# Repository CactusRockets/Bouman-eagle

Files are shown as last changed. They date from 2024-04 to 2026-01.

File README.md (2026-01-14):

# Avionics Boards for the Bouman-3KM Rocket

This repository contains the design files for the avionics boards used in the **Bouman 3 km rocket**, developed by **Cactus Rockets Design**.

## Description

The avionics system is composed of the following boards:

- **COTS Board**
- **Processing Board**
- **Actuation Board**
- **Battery Board**

The **COTS Board** is responsible for measuring pressure, altitude, acceleration, and the rocket’s orientation.

The **Processing Board** handles the processing of data received from the COTS board and the GPS module, stores this data, and transmits it via telemetry.

The **Actuation Board** contains the circuitry required to correctly activate the squibs (skibs) used in the recovery system.

The **Battery Board** distributes the battery voltages to connectors so they can be easily used by the other boards.

> **Note:** All board files can be opened using **Autodesk Eagle** software.

## Schematics and Layouts

### COTS Board
cots1
cots2

### Processing Board
processamento1
processamento2

### Actuation Board
acionamento1
acionamento2

### Battery Board
baterias1
baterias2

## System Operation

Both the **COTS Board** and the **Processing Board** include activation switches. The system startup sequence is as follows:

1. Activate the switch on the COTS Board.
2. Activate the switch on the Processing Board.

After each sensor reading, the data is stored on a microSD card and transmitted via telemetry.

When the COTS board detects the rocket’s descent, it sends a signal to the Actuation Board, which then triggers the squib responsible for deploying the **drogue parachute**.

During the descent with only the drogue parachute deployed, once the rocket reaches an altitude below **500 meters**, the system detects this condition and activates the second squib. This action deploys the **main parachute**, ensuring a stable and controlled descent of the rocket until touchdown.

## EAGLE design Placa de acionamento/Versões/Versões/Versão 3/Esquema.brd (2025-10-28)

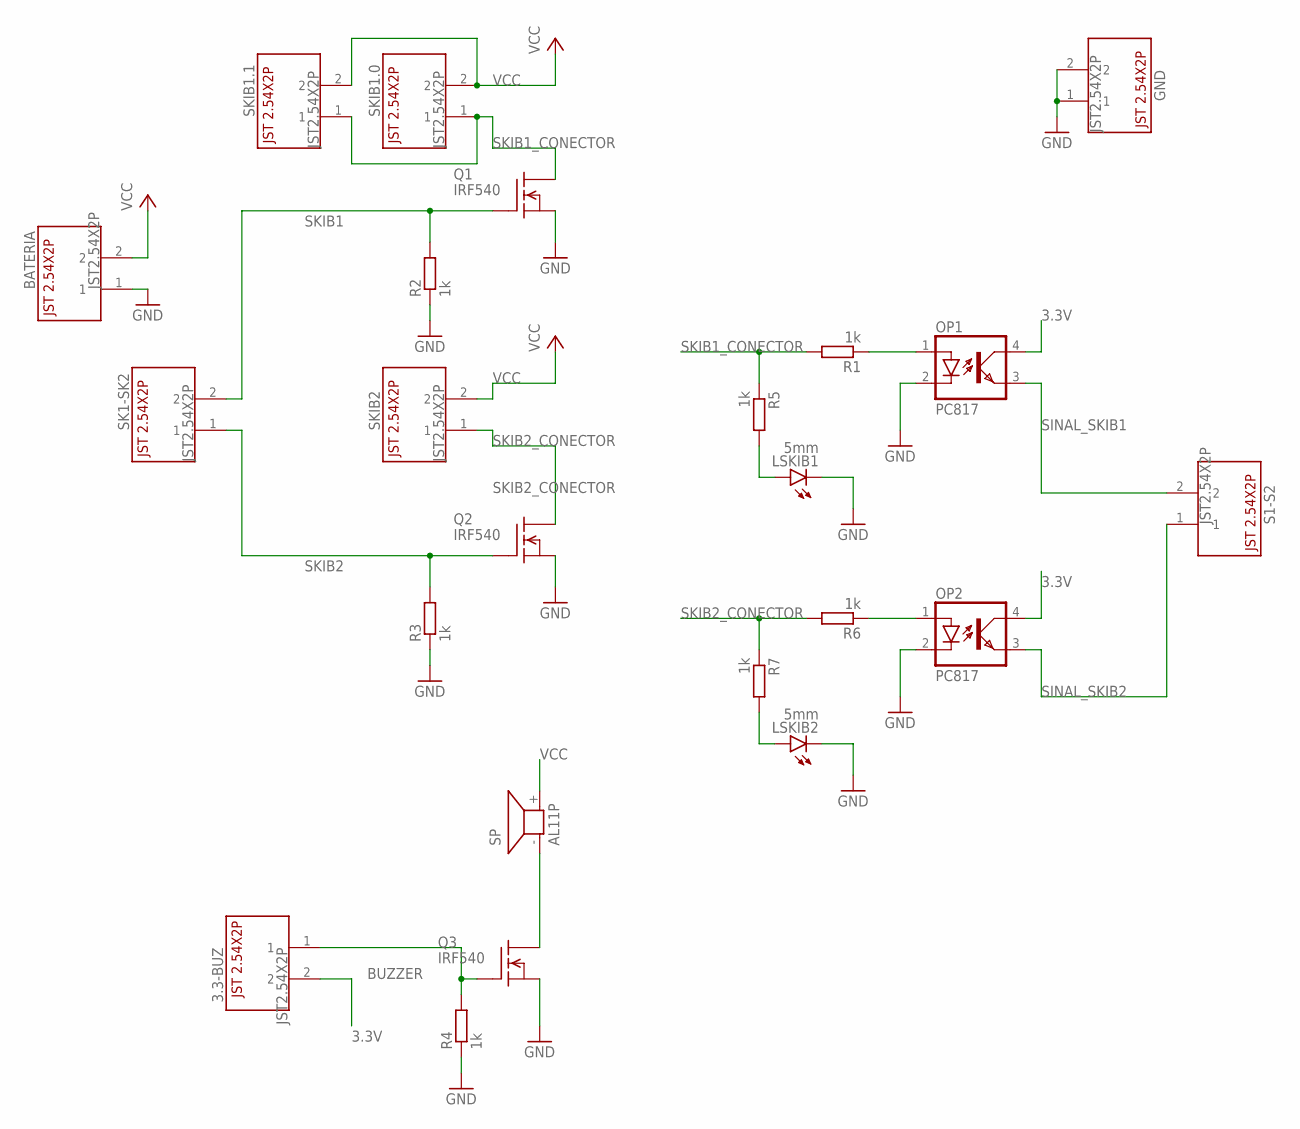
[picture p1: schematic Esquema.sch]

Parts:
3.3-BUZ: JST2.54X2P; JST2.54X2P_FOOTPRINT
BATERIA: JST2.54X2P; JST2.54X2P_FOOTPRINT
GND: JST2.54X2P; JST2.54X2P_FOOTPRINT
LSKIB1, LSKIB2: 5mm; LED5MM
OP1, OP2: PC817; DIL04
Q1, Q2, Q3: IRF540; TO220
R1, R2, R3, R4, R5, R6, R7: 1k; 0207/10
S1-S2: JST2.54X2P; JST2.54X2P_FOOTPRINT
SK1-SK2: JST2.54X2P; JST2.54X2P_FOOTPRINT
SKIB1.0, SKIB1.1, SKIB2: JST2.54X2P; JST2.54X2P_FOOTPRINT
SP: AL11P

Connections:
3.3V: 3.3-BUZ.2, OP1.4 (COL), OP2.4 (COL)
BUZZER: 3.3-BUZ.1, Q3.1 (G), R4.2
GND: BATERIA.1, GND.1, GND.2, LSKIB1.K (C), LSKIB2.K (C), OP1.2 (C), OP2.2 (C), Q1.3 (S), Q2.3 (S), Q3.3 (S), R2.1, R3.1, R4.1
unnamed: LSKIB2.A, R7.2
unnamed: Q3.2 (D), SP.- (1)
unnamed: LSKIB1.A, R5.2
unnamed: OP1.1 (A), R1.1
unnamed: OP2.1 (A), R6.1
SINAL_SKIB1: OP1.3 (EMIT), S1-S2.2
SINAL_SKIB2: OP2.3 (EMIT), S1-S2.1
SKIB1: Q1.1 (G), R2.2, SK1-SK2.2
SKIB1_CONECTOR: Q1.2 (D), R1.2, R5.1, SKIB1.0.1, SKIB1.1.1
SKIB2: Q2.1 (G), R3.2, SK1-SK2.1
SKIB2_CONECTOR: Q2.2 (D), R6.2, R7.1, SKIB2.1
VCC: BATERIA.2, SKIB1.0.2, SKIB1.1.2, SKIB2.2, SP.+ (2)

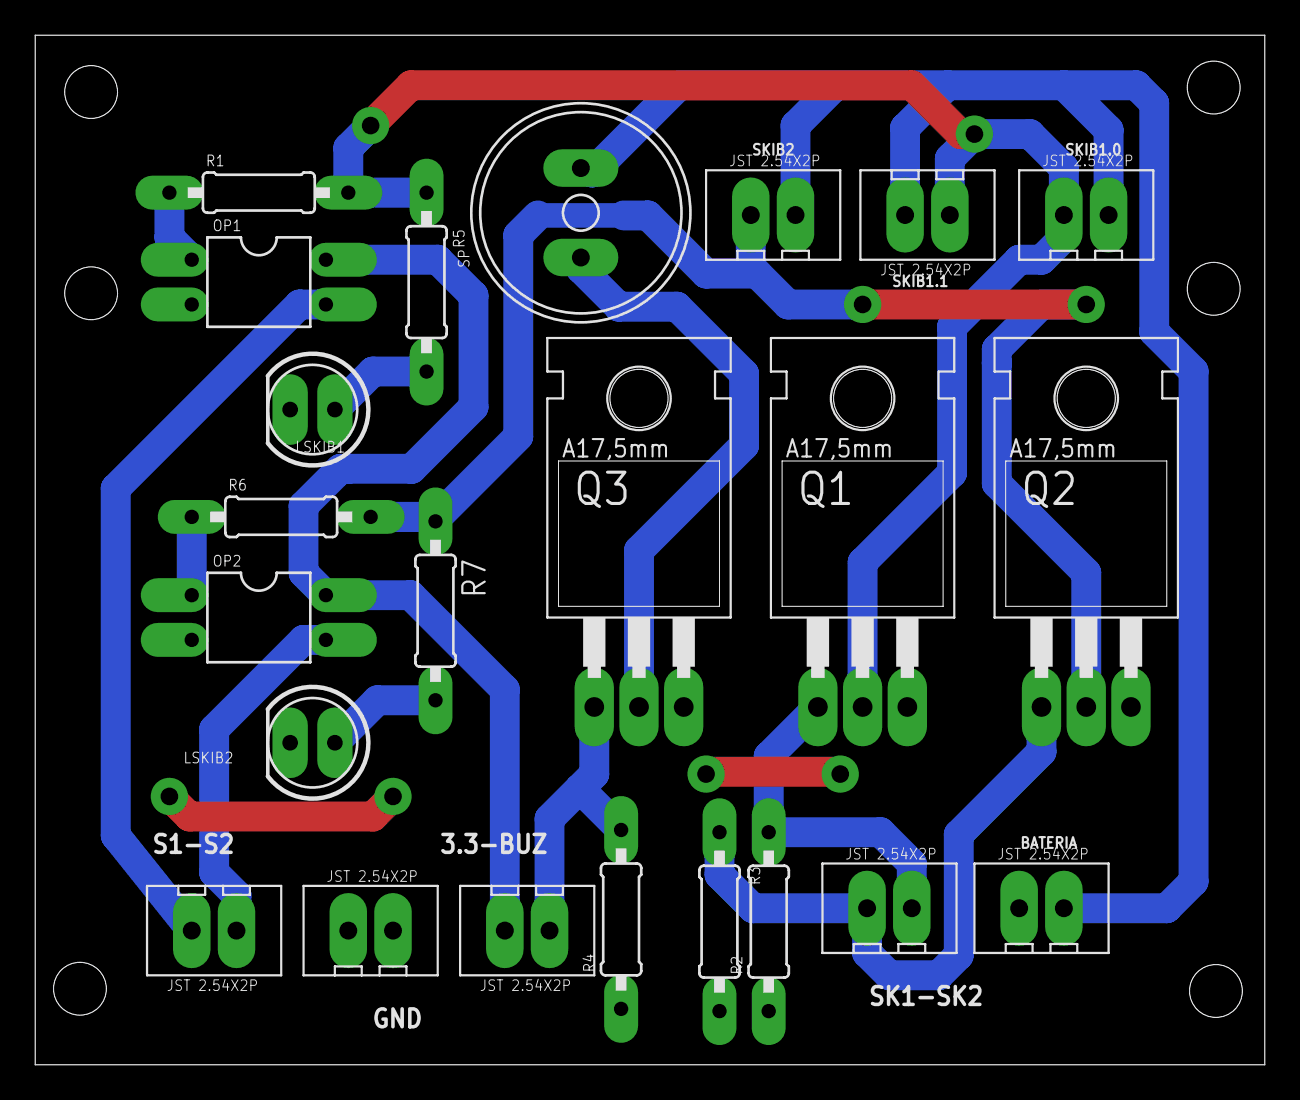
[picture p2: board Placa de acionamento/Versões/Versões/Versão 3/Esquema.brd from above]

Board: 2 copper layers, 69.8 x 58.5 mm, 23 parts (0 on the bottom side), 15 nets.

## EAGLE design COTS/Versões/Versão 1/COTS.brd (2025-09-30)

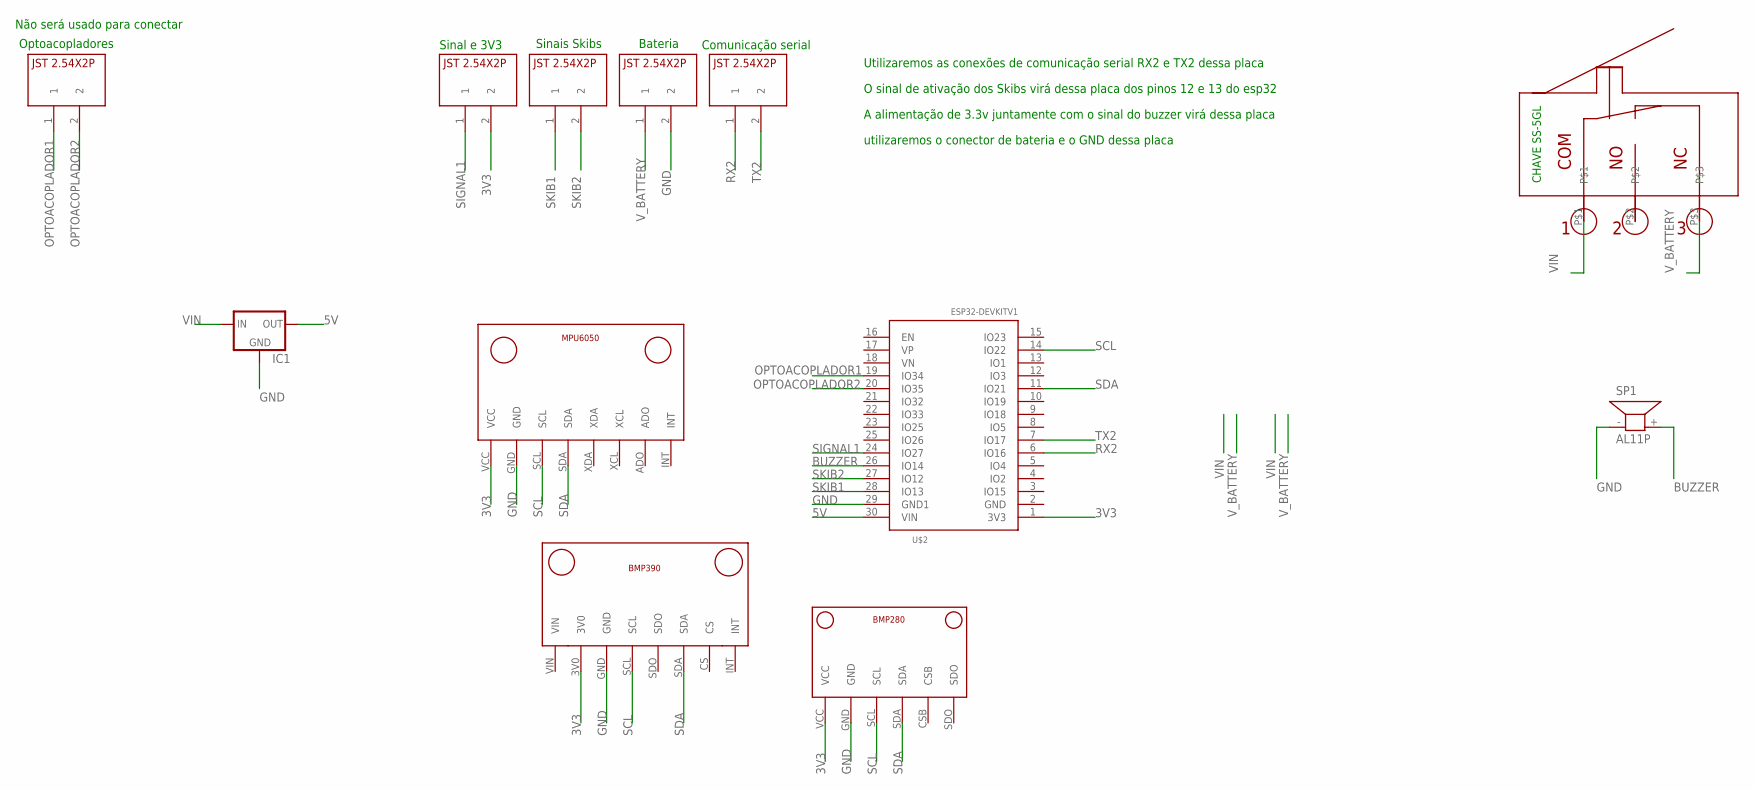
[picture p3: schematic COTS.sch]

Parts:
IC1: 78XXL
SP1: AL11P
U$1: MPU6050V1; MPU6050_FOOTPRINT
U$2: ESP32DEVKITV1; ESP32-DEVKITV1
U$3: BMP390V1; BMP390_FOOTPRINT
U$4, U$5, U$6, U$7, U$9: JST2.54X2P; JST2.54X2P_FOOTPRINT
U$8: CHAVE_SS-5GL; CHAVESS-5GL
U$10: BMP280V1; BMP280_FOOTPRINT

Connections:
3V3: U$1.VCC, U$2.1 (3V3), U$3.3V0, U$5.2, U$10.VCC
5V: IC1.OUT, U$2.30 (VIN)
BUZZER: SP1.+ (2), U$2.26 (IO14)
GND: IC1.GND, SP1.- (1), U$1.GND, U$2.29 (GND1), U$3.GND, U$6.2, U$10.GND
OPTOACOPLADOR1: U$2.19 (IO34), U$9.1
OPTOACOPLADOR2: U$2.20 (IO35), U$9.2
RX2: U$2.6 (IO16), U$7.1
SCL: U$1.SCL, U$2.14 (IO22), U$3.SCL, U$10.SCL
SDA: U$1.SDA, U$2.11 (IO21), U$3.SDA, U$10.SDA
SIGNAL1: U$2.24 (IO27), U$5.1
SKIB1: U$2.28 (IO13), U$4.1
SKIB2: U$2.27 (IO12), U$4.2
TX2: U$2.7 (IO17), U$7.2
VIN: IC1.IN, U$8.P$1
V_BATTERY: U$6.1, U$8.P$3

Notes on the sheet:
Sinais Skibs
Sinal e 3V3
Bateria
Comunicação serial
Optoacopladores
Utilizaremos as conexões de comunicação serial RX2 e TX2 dessa placa
O sinal de ativação dos Skibs virá dessa placa dos pinos 12 e 13 do esp32
A alimentação de 3.3v juntamente com o sinal do buzzer virá dessa placa
utilizaremos o conector de bateria e o GND dessa placa
Não será usado para conectar

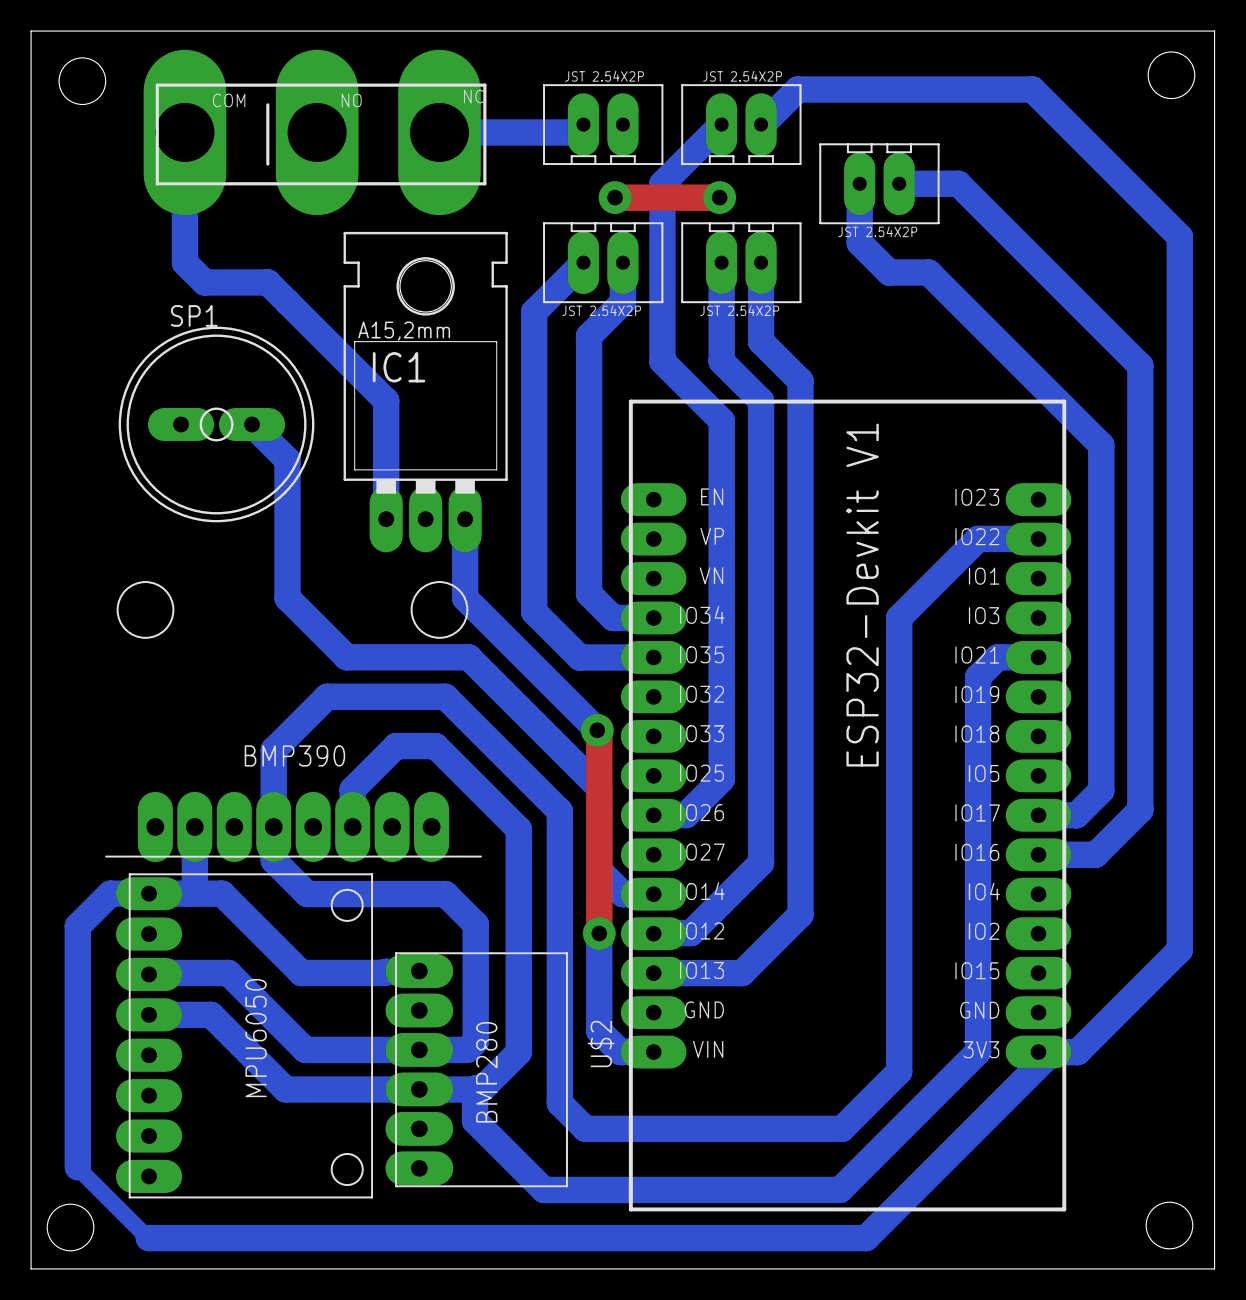
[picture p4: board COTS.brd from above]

Board: 2 copper layers, 76.2 x 79.7 mm, 12 parts (0 on the bottom side), 15 nets.

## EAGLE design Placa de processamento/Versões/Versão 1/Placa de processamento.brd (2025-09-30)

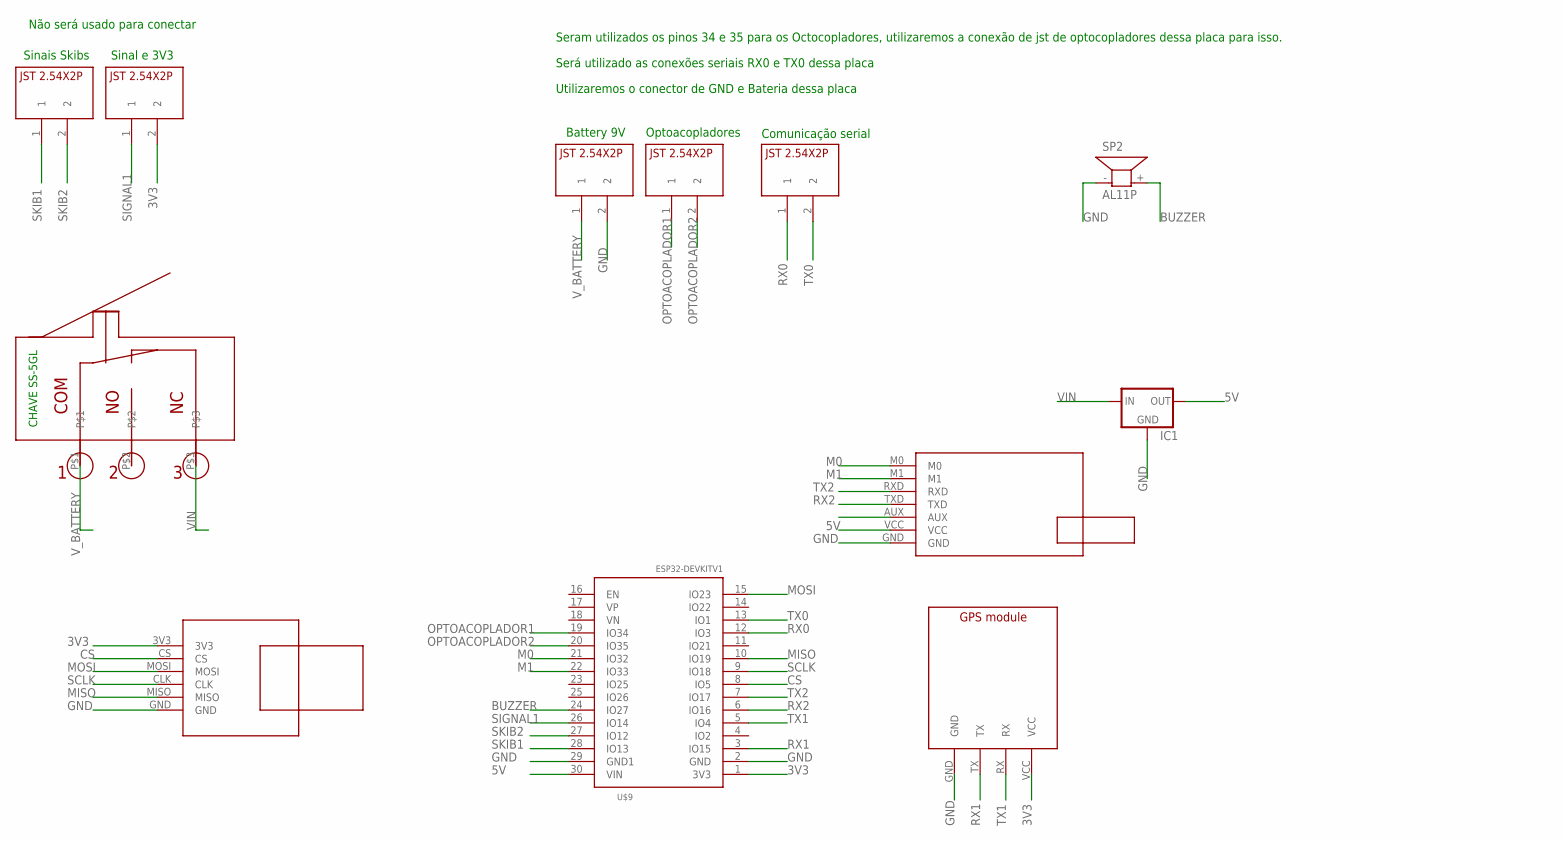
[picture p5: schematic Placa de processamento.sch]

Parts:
IC1: 78XXL
SP2: AL11P
U$2: MICROSD_SMALL_READER; MICROSD_SMALL_READER_FOOTPRINT
U$3, U$4, U$5, U$6, U$10: JST2.54X2P; JST2.54X2P_FOOTPRINT
U$7: GPS_MODULE; GPS_MODULE_FOOTPRINT
U$8: E22-400T30D; E22-400T30D_FOOTPRINT
U$9: ESP32DEVKITV1; ESP32-DEVKITV1
U$11: CHAVE_SS-5GL; CHAVESS-5GL

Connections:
3V3: U$2.3V3, U$5.2, U$7.VCC, U$9.1 (3V3)
5V: IC1.OUT, U$8.VCC, U$9.30 (VIN)
BUZZER: SP2.+ (2), U$9.24 (IO27)
CS: U$2.CS, U$9.8 (IO5)
GND: IC1.GND, SP2.- (1), U$2.GND, U$3.2, U$7.GND, U$8.GND, U$9.2 (GND), U$9.29 (GND1)
M0: U$8.M0, U$9.21 (IO32)
M1: U$8.M1, U$9.22 (IO33)
MISO: U$2.MISO, U$9.10 (IO19)
MOSI: U$2.MOSI, U$9.15 (IO23)
OPTOACOPLADOR1: U$6.1, U$9.19 (IO34)
OPTOACOPLADOR2: U$6.2, U$9.20 (IO35)
RX0: U$9.12 (IO3), U$10.1
RX1: U$7.TX, U$9.3 (IO15)
RX2: U$8.TXD, U$9.6 (IO16)
SCLK: U$2.CLK, U$9.9 (IO18)
SIGNAL1: U$5.1, U$9.26 (IO14)
SKIB1: U$4.1, U$9.28 (IO13)
SKIB2: U$4.2, U$9.27 (IO12)
TX0: U$9.13 (IO1), U$10.2
TX1: U$7.RX, U$9.5 (IO4)
TX2: U$8.RXD, U$9.7 (IO17)
VIN: IC1.IN, U$11.P$3
V_BATTERY: U$3.1, U$11.P$1

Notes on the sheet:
Battery 9V
Sinais Skibs
Sinal e 3V3
Optoacopladores
Comunicação serial
Seram utilizados os pinos 34 e 35 para os Octocopladores, utilizaremos a conexão de jst de optocopladores dessa placa para isso.
Será utilizado as conexões seriais RX0 e TX0 dessa placa
Utilizaremos o conector de GND e Bateria dessa placa
Não será usado para conectar

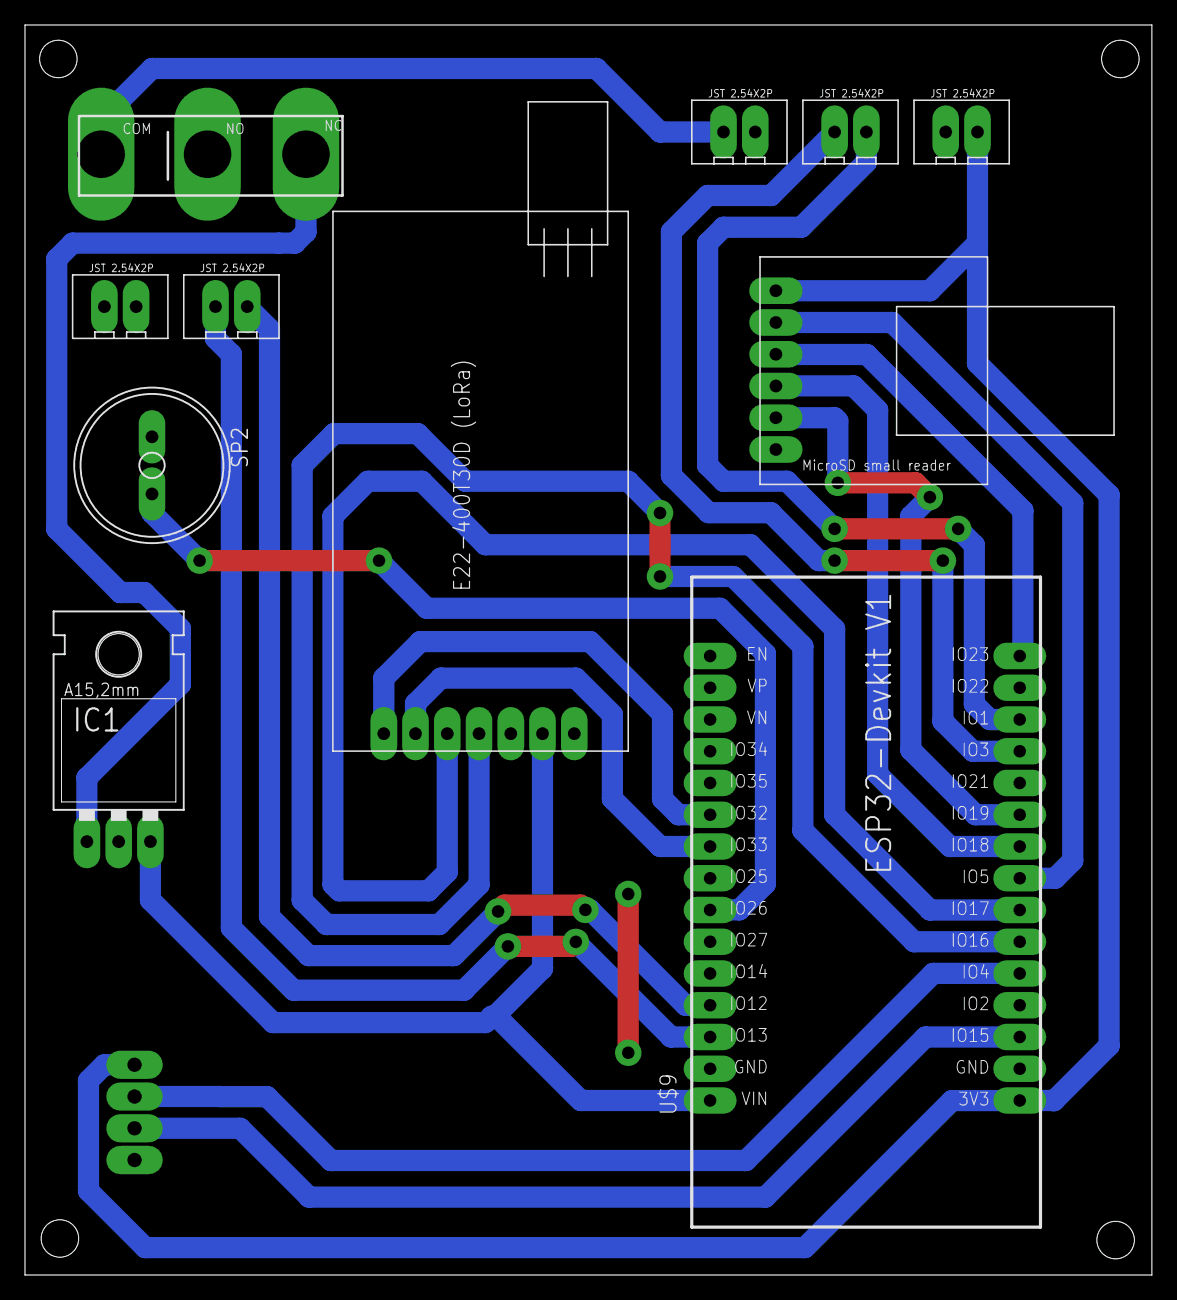
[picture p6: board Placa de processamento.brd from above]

Board: 2 copper layers, 90.2 x 100.0 mm, 12 parts (1 on the bottom side), 23 nets.

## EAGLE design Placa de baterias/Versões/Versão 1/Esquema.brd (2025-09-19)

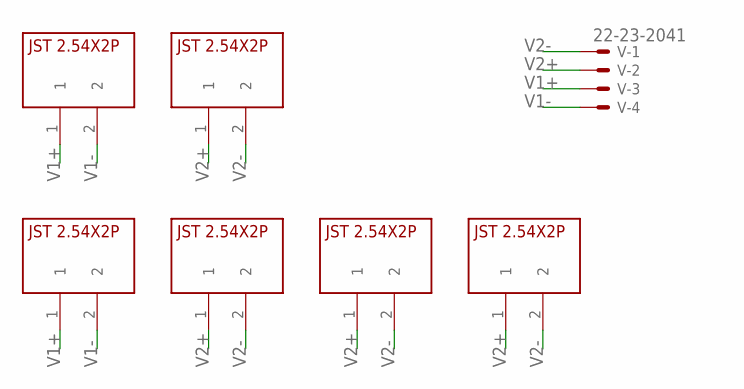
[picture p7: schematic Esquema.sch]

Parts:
U$1, U$2, U$3, U$4, U$5, U$6: JST2.54X2P; JST2.54X2P_FOOTPRINT
V: 22-23-2041

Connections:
V1+: U$1.1, U$4.1, V.3
V1-: U$1.2, U$4.2, V.4
V2+: U$2.1, U$3.1, U$5.1, U$6.1, V.2
V2-: U$2.2, U$3.2, U$5.2, U$6.2, V.1

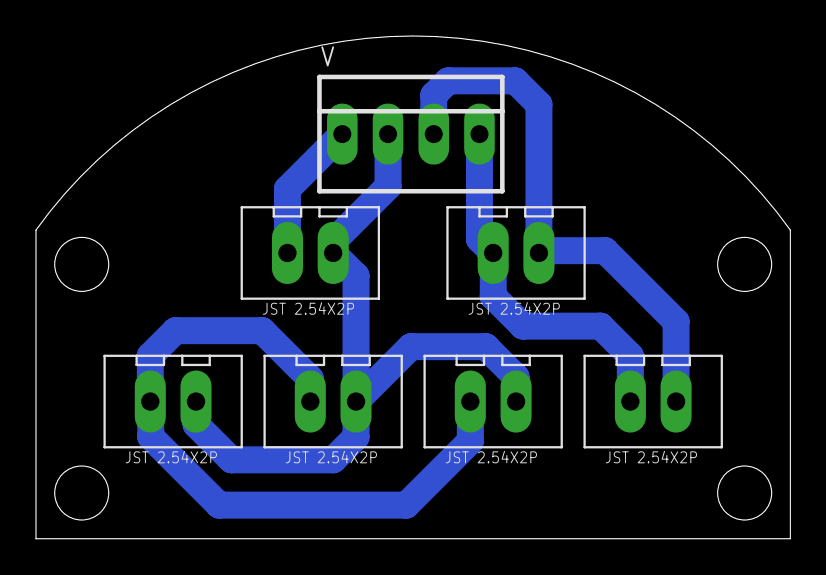
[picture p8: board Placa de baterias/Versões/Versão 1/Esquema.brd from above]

Board: 2 copper layers, 41.9 x 27.9 mm, 7 parts (0 on the bottom side), 4 nets.

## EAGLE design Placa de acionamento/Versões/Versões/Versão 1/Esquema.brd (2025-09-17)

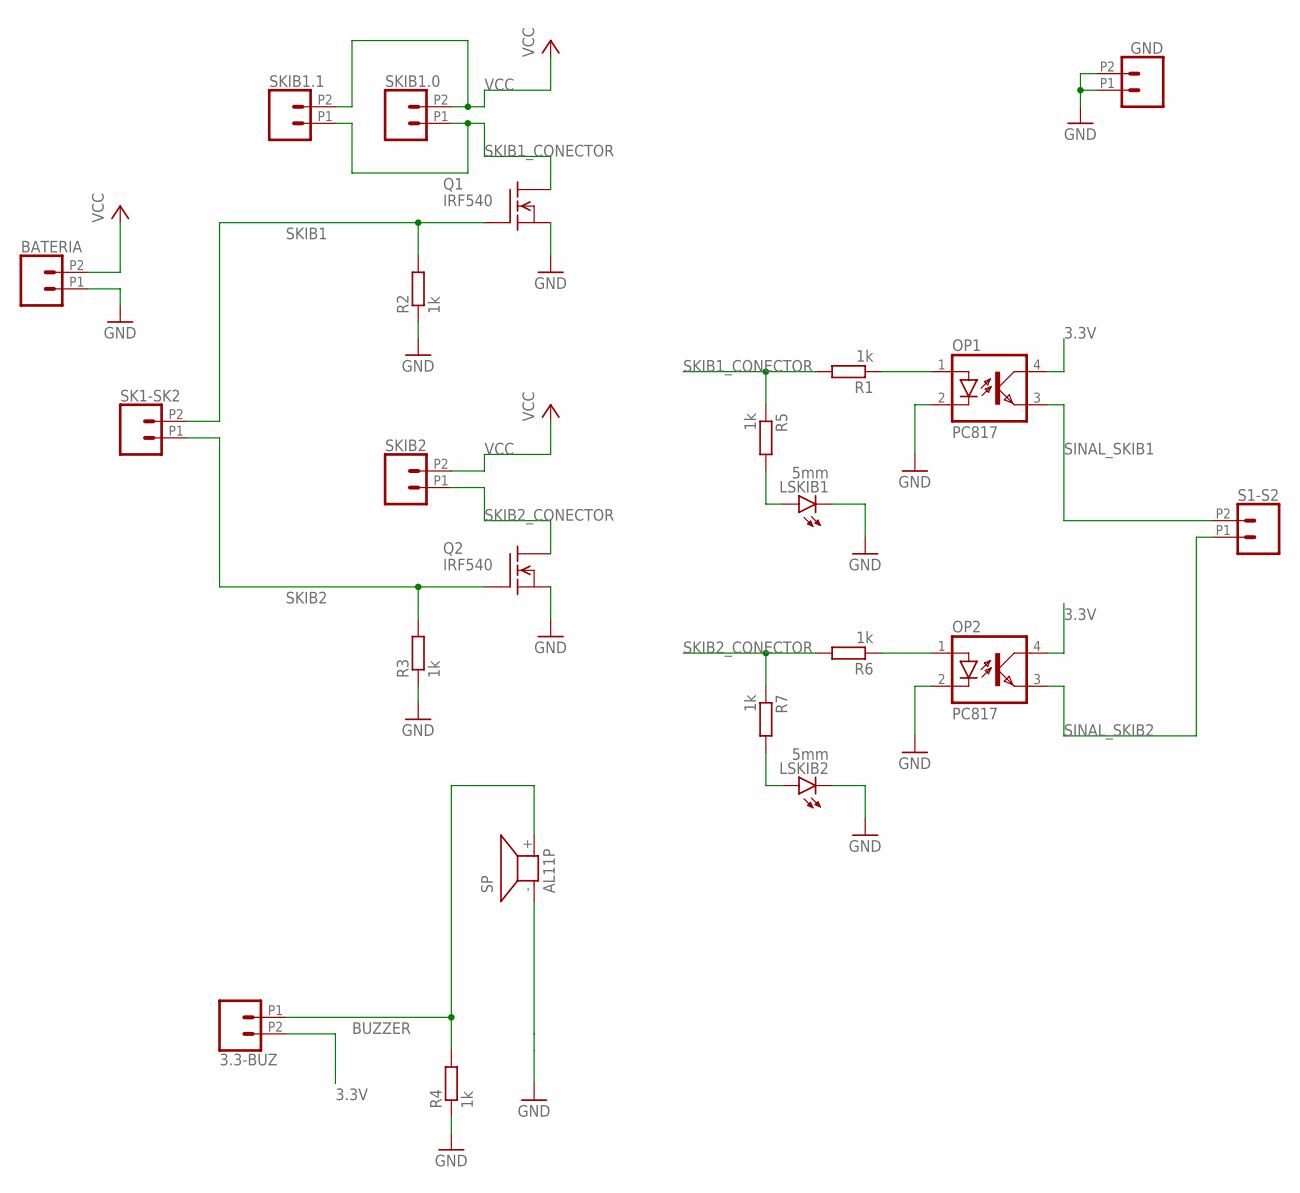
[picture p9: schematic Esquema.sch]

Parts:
3.3-BUZ: CONN_022.54MM_SCREWTERM; 1X02_2.54_SCREWTERM
BATERIA: CONN_022.54MM_SCREWTERM; 1X02_2.54_SCREWTERM
GND: CONN_022.54MM_SCREWTERM; 1X02_2.54_SCREWTERM
LSKIB1, LSKIB2: 5mm; LED5MM
OP1, OP2: PC817; DIL04
Q1, Q2: IRF540; TO220
R1, R2, R3, R4, R5, R6, R7: 1k; 0207/10
S1-S2: CONN_022.54MM_SCREWTERM; 1X02_2.54_SCREWTERM
SK1-SK2: CONN_022.54MM_SCREWTERM; 1X02_2.54_SCREWTERM
SKIB1.0, SKIB1.1, SKIB2: CONN_022.54MM_SCREWTERM; 1X02_2.54_SCREWTERM
SP: AL11P

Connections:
3.3V: 3.3-BUZ.P2 (2), OP1.4 (COL), OP2.4 (COL)
BUZZER: 3.3-BUZ.P1 (1), R4.2, SP.+ (2)
GND: BATERIA.P1 (1), GND.P1 (1), GND.P2 (2), LSKIB1.K (C), LSKIB2.K (C), OP1.2 (C), OP2.2 (C), Q1.3 (S), Q2.3 (S), R2.1, R3.1, R4.1, SP.- (1)
unnamed: LSKIB2.A, R7.2
unnamed: LSKIB1.A, R5.2
unnamed: OP1.1 (A), R1.1
unnamed: OP2.1 (A), R6.1
SINAL_SKIB1: OP1.3 (EMIT), S1-S2.P2 (2)
SINAL_SKIB2: OP2.3 (EMIT), S1-S2.P1 (1)
SKIB1: Q1.1 (G), R2.2, SK1-SK2.P2 (2)
SKIB1_CONECTOR: Q1.2 (D), R1.2, R5.1, SKIB1.0.P1 (1), SKIB1.1.P1 (1)
SKIB2: Q2.1 (G), R3.2, SK1-SK2.P1 (1)
SKIB2_CONECTOR: Q2.2 (D), R6.2, R7.1, SKIB2.P1 (1)
VCC: BATERIA.P2 (2), SKIB1.0.P2 (2), SKIB1.1.P2 (2), SKIB2.P2 (2)

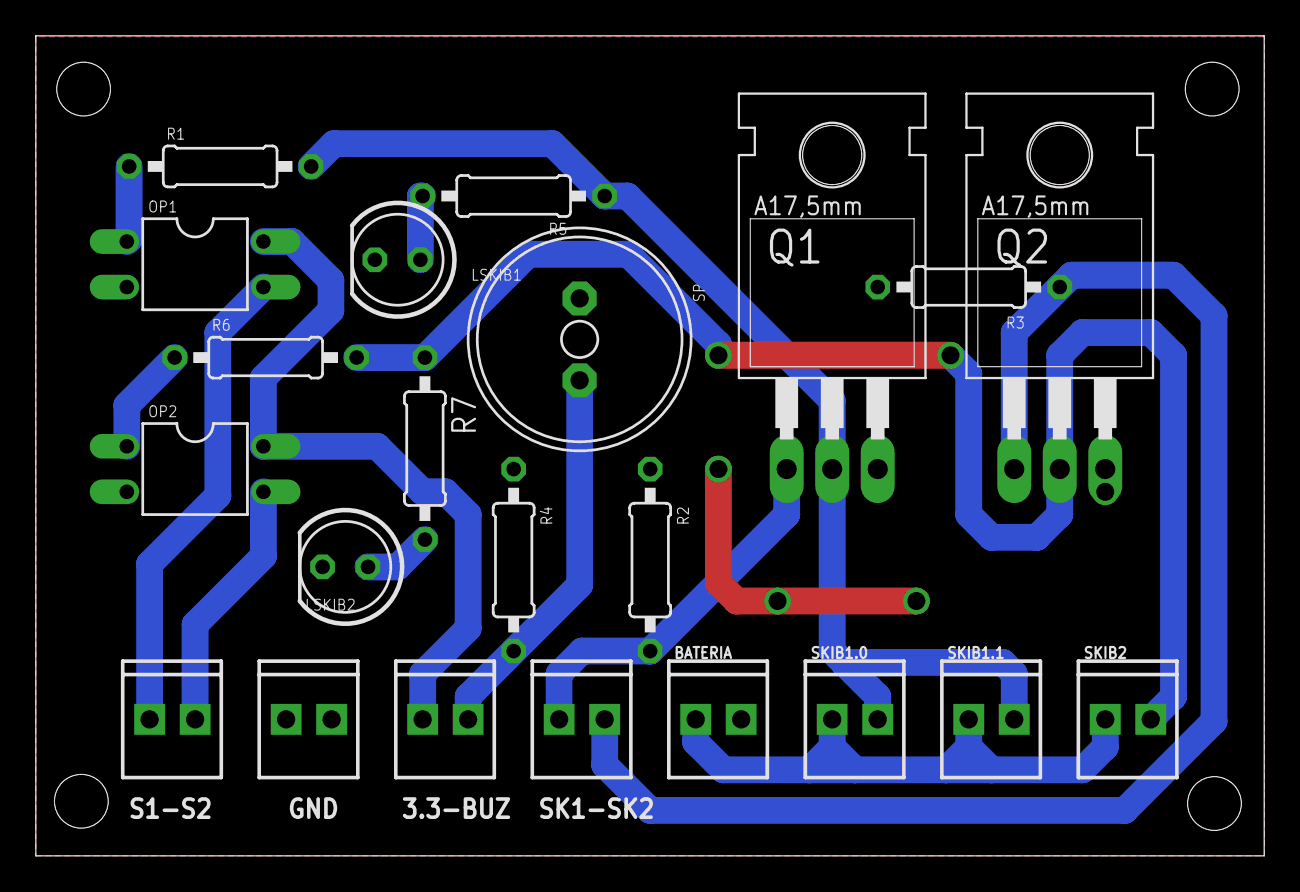
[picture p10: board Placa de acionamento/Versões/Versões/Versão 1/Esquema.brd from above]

Board: 2 copper layers, 68.6 x 45.8 mm, 22 parts (0 on the bottom side), 14 nets.

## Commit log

2024-04-20 Upload para o Fusion
    [COTS.brd, Esquema 02 guilherme.brd]
2024-04-20 Conexões em placa de processamento
    [Placa de processamento.brd]
2024-04-20 Começo do roteamento
    [Placa de processamento.brd]
2024-04-21 Update do roteamento
    [Placa de processamento.brd, Placa de processamento.sch]
2024-04-23 Atualização
    [COTS.brd, COTS.sch, Placa de processamento.brd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]
2024-10-04 feat: ajustes na placa em conexões
    [COTS.sch, Placa de processamento.sch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]
2025-09-06 FEAT: adicionando versão 2 das placas
    [COTS.brd, COTS.sch, Esquema.brd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]
2025-09-06 CHORE: adicionando modelos 3D
    [COTS.brd, COTS.sch, Esquema.brd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]
2025-09-07 FEAT: adicionando regulador de tensao 5V
    [COTS.brd, COTS.sch]
2025-09-09 FIX: consertando chave de acionamento
    [COTS.brd, COTS.sch, Esquema.brd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]
2025-09-09 placa de baterias
    [Esquema.brd, Esquema.sch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]
2025-09-12 atualização placas
    [COTS.brd, COTS.sch, Placa de processamento.brd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]
2025-09-17 CHORE: aplicando design rules da cactus
    [COTS.brd]
2025-09-18 CHORE: colocando pads ovais
    [COTS.brd, COTS.sch]
2025-09-19 CHORE: adicionando pads ovais na placa de processamento
    [Esquema.brd, Esquema.sch, Placa de processamento.brd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]
2025-09-24 CHORE: trocando conectores JST
    [Esquema.brd, Esquema.sch]
2025-09-24 CHORE: adicionando pads ovais
    [Esquema.brd, Esquema.sch]
2025-09-29 FIX: movendo LoRa para melhor posição
    [COTS.brd, COTS.sch, Placa de processamento.brd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]
2025-09-30 Ajuste no 3D do BMP
    O BMP foi ajustado, para ficar posicionado na parte superior da placa
    [COTS.brd, COTS.sch]
2025-10-28 placa de acionamento
    [Esquema.brd, Esquema.sch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]

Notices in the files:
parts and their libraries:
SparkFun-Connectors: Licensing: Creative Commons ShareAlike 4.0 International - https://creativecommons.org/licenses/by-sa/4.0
